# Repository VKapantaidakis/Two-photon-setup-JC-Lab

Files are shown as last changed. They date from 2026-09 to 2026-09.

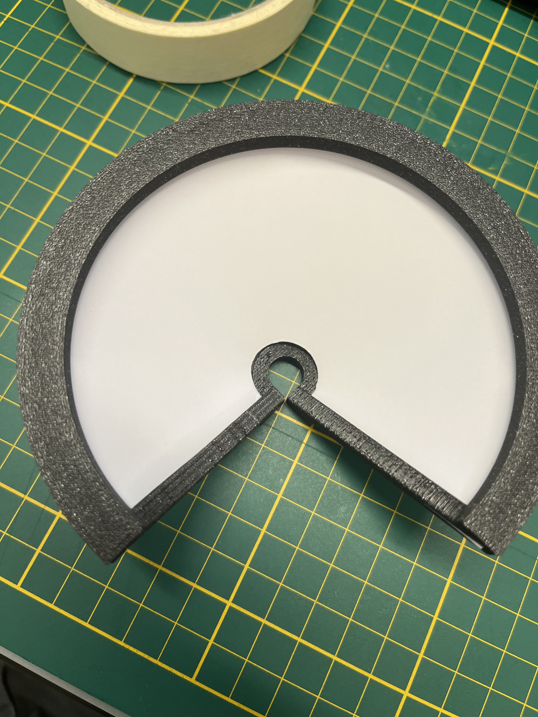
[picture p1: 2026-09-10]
Thesis setup/figures/TWO_PHOTON_SCREEN2.jpeg

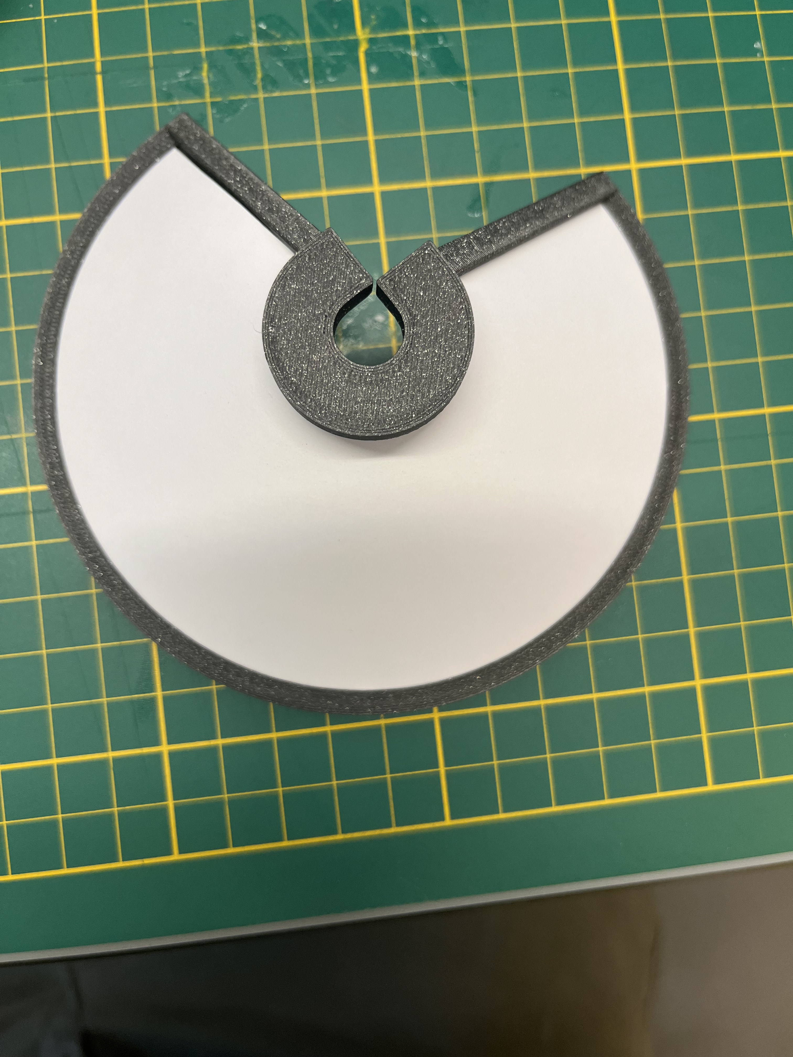
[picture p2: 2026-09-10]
Thesis setup/figures/TWO_PHOTON_SCREEN1.jpeg

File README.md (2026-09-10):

# Two Photon Setup — JC Lab

Two-photon imaging and behaviour setup for tethered *Drosophila*. A **Basler GigE camera** tracks a spherical treadmill through **FicTrac**, a **ViRMEn** virtual world is projected onto a **conical screen**, and an **Arduino** timestamps every two-photon frame trigger so imaging and behaviour can be aligned offline.

**Author:** Vasilis Kapantaidakis
**Lab:** JC Lab (Billeter Lab), Groningen Institute for Evolutionary Life Sciences (GELIFES), University of Groningen
**Experiment type:** two-photon calcium imaging with simultaneous visual-stimulation behaviour in tethered *Drosophila melanogaster* on a spherical treadmill
**Platform:** Ubuntu 24.04 LTS · MATLAB R2014b · FicTrac · ViRMEn · Basler Pylon · Arduino

Everything here was run on a real machine and the commands are reproduced verbatim, including the workarounds for the awkward combinations (a 2014 MATLAB on a 2024 Linux, a Pylon SDK newer than the FicTrac fork expects, GigE over a USB-Ethernet adapter).

> ### ▶ Just want to run an experiment today?
> **[RUN-AN-EXPERIMENT.md](RUN-AN-EXPERIMENT.md)** — the step-by-step checklist: open MATLAB, run the config, start FicTrac, start the scan.
> The numbered `docs/` below are for building the rig from scratch.

---

## Hardware

| Component | Model / notes |
|---|---|
| Camera | Basler **acA1300-60gm**, GigE (Ethernet), 1280×1024 @ 60 fps |
| Camera link | RTL8153 USB-Ethernet adapter (see the MTU caveat in [01](docs/01-basler-camera.md)) |
| Microcontroller | Arduino Uno R3 |
| RTC | DS3231 (I²C) |
| Environment sensor | DHT22 |
| Illumination | IR LED array via IRF520 MOSFET module |
| Projection | projector onto a 3D-printed conical screen ([07](docs/07-3d-printed-parts.md)) |
| Treadmill | patterned foam sphere on an air support |
| Host | Dell Pro 14, Ubuntu 24.04.4 LTS |

## Software stack

```
Basler camera ──GigE──> FicTrac ──(TCP, optional closed loop)──> ViRMEn (MATLAB)
                                                                      │
2P frame TTL ──> Arduino ──USB serial──> arduinoFrameLog ─────────────┘
                                              │
                                              └──> per-frame CSV logs
```

In the **WhiteBack → BlackChamber** protocol documented here, ViRMEn's movement function is `moveWithKeyboard` — the fly does not drive the world. FicTrac records ball motion alongside; closed-loop is a separate protocol.

## Replicate it — follow in order

| # | Document | What it gets you |
|---|---|---|
| ▶ | **[Run an experiment](RUN-AN-EXPERIMENT.md)** | **daily checklist once the rig is built** |
| 00 | [User & OS setup](docs/00-user-setup.md) | Ubuntu user, groups, **Xorg session**, folder layout |
| 01 | [Basler camera](docs/01-basler-camera.md) | Pylon SDK, GigE network, live image |
| 02 | [FicTrac](docs/02-fictrac.md) | Built against Pylon, calibrated, tracking |
| 03 | [MATLAB R2014b](docs/03-matlab.md) | Installed, licensed, **two launchers** |
| 04 | [ViRMEn](docs/04-virmen.md) | Compiled for Linux, worlds rendering |
| 05 | [Arduino / DAQ](docs/05-arduino-daq.md) | Sketch, wiring, serial into MATLAB |
| 06 | [Experiment workflow](docs/06-experiment-workflow.md) | Running a session end to end |
| 07 | [3D printed parts](docs/07-3d-printed-parts.md) | Conical screen and mounts |
| 99 | [Troubleshooting](docs/99-troubleshooting.md) | Every error we hit, and its fix |

## Repository layout

```
matlab/     experiment scripts (see docs/06)
arduino/    daq_frame_logger_v6 sketch
patches/    source patches for FicTrac and ViRMEn
setup/      udev rule, desktop launchers
hardware/   3D print files
docs/       the guides above
```

## Five things that will cost you a day if you skip them

1. **Use an Xorg session, not Wayland.** FicTrac's GUI dies on Wayland with a protocol error. [→ 00](docs/00-user-setup.md)
2. **You need two MATLAB launchers.** `-softwareopengl` makes ViRMEn's design panels render but **segfaults** when an experiment runs; without it the experiment runs but the panels are blank. They cannot be reconciled. [→ 03](docs/03-matlab.md)
3. **MATLAB R2014b on Linux only sees `/dev/ttyS*`.** Your Arduino on `/dev/ttyACM0` is invisible until you symlink it. [→ 05](docs/05-arduino-daq.md)
4. **Do not enable jumbo frames** on a USB-Ethernet adapter. Pylon's optimiser sets MTU 9000, ping still works, and video silently dies. [→ 01](docs/01-basler-camera.md)
5. **One program per device.** Pylon Viewer blocks FicTrac; the DAQ monitor blocks the experiment script. Wait ~8 s after killing a client for the GigE heartbeat to expire. [→ 99](docs/99-troubleshooting.md)

## Citing / reusing this setup

If this documentation helps you build or repair a rig, a note or citation is appreciated:

> Kapantaidakis, V. *Two Photon Setup — JC Lab: a replication guide for a tethered-fly
> two-photon imaging and conical visual stimulation rig.* JC Lab (Billeter Lab),
> University of Groningen, 2026. https://github.com/VKapantaidakis/Two-photon-setup-JC-Lab

The 3D printed optomechanics are a third-party design — see [docs/07](docs/07-3d-printed-parts.md) for attribution.

## Contact

**If you have problems with anything in this repository, contact Vasilis Kapantaidakis:**

- **vaskapant@gmail.com**
- **v.kapantaidakis@student.rug.nl**

JC Lab (Billeter Lab), University of Groningen.

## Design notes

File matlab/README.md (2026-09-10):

# matlab/

Install these into `~/Documents/MATLAB/virmen/experiments/`.

| File | Role |
|---|---|
| `MasterSwitchByDAQ_WhiteBack_BlackChamber.m` | main experiment script (WhiteBack -> BlackChamber) |
| `WhiteBack.m` / `BlackChamber.m` | phase logic; end after `vr.frameThreshold` frames |
| `WhiteBack.mat` / `BlackChamber.mat` | ViRMEn visual worlds |
| `arduinoFrameLog.m` | the single serial reader; logging, live panel, CSV export |
| `plotSession.m` | post-hoc plots + per-phase summary |
| `daq_frame_monitor_v2.m` | standalone DAQ tester (do NOT run alongside the master script) |

All are MATLAB **R2014b** compatible: legacy `serial()` API, no `serialport`,
no `datetime`, no `yyaxis`, and no local functions inside script files.

See [docs/06-experiment-workflow.md](../docs/06-experiment-workflow.md).

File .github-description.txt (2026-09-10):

Paste this into the repo's "About" box on GitHub (gear icon, top right):

DESCRIPTION
-----------
Two-photon imaging + visual stimulation rig for tethered Drosophila by Vasilis Kapantaidakis (JC Lab, University of Groningen). Basler GigE camera, FicTrac treadmill tracking, ViRMEn worlds on a conical screen, Arduino frame-trigger sync. Full setup and replication guide for Ubuntu 24.04 + MATLAB R2014b.

TOPICS (add these tags)
-----------------------
drosophila  two-photon  calcium-imaging  neuroscience  virtual-reality
fictrac  virmen  matlab  arduino  basler  pylon  behaviour  ubuntu
spherical-treadmill  visual-stimulation

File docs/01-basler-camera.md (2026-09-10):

# 01 — Basler GigE camera (Pylon SDK)

Getting a **Basler acA1300-60gm** GigE camera streaming on Ubuntu 24.04.

Pylon is Basler's SDK — the equivalent of Spinnaker for FLIR cameras. If you are adapting a Spinnaker-based protocol, note that **none of the Spinnaker workarounds apply**: no spack, no ffmpeg 4, no `usbfs_memory` service (that is USB3-only), no `flirimaging` group.

---

## 1. Install the Pylon SDK

Download from the [Basler website](https://www.baslerweb.com/en/software/pylon/) (free account required). Install to **`/opt/pylon`** — the FicTrac build in [02](02-fictrac.md) expects that path.

```bash
# .deb package (installs to /opt/pylon by default)
sudo apt install ./pylon_*_amd64.deb

# or from the tarball
cd ~/Downloads
tar -xzf pylon_*_x86_64_setup.tar.gz
sudo mkdir -p /opt/pylon
sudo tar -C /opt/pylon -xzf pylon-*.tar.gz
```

Load the environment (add to `~/.bashrc` so it persists):

```bash
source /opt/pylon/bin/pylon-setup-env.sh /opt/pylon
echo 'source /opt/pylon/bin/pylon-setup-env.sh /opt/pylon' >> ~/.bashrc
echo $PYLON_ROOT          # expect: /opt/pylon
```

Verify the C++ SDK and the GigE transport layer are present — FicTrac links against these:

```bash
ls /opt/pylon/include/pylon/PylonBase.h
ls /opt/pylon/lib | grep libpylon_TL_gige
```

If Pylon Viewer later fails with an `xcb` plugin error, install the Qt runtime pieces:

```bash
sudo apt-get install -y libxcb-xinerama0 libxcb-xinput0 libxcb-cursor0 \
  libxkbcommon-x11-0 libqt5gui5 libqt5widgets5
```

> **Modern Pylon note.** Pylon 7/8 (`libpylonbase.so.12`) reorganised its headers: the transport-specific ones under `pylon/usb/` no longer exist. Use the transport-agnostic `pylon/InstantCameraArray.h` and `Pylon::CInstantCamera`, which drive **both** GigE and USB3. This is exactly the patch FicTrac needs — see [02](02-fictrac.md).

## 2. Network configuration

A GigE camera is a network device on a dedicated link. Reference configuration:

```
enx00e04c68131b   RTL8153 USB-Ethernet, 192.168.4.2/24, MTU 1500, 1000 Mbps  <- CAMERA
  camera:         192.168.4.3, MAC 00:30:53:2c:a0:de   (00:30:53 = Basler OUI)
enp0s31f6         onboard Ethernet, DOWN (unused)
wlp44s0f0         WiFi — the MATLAB licence is host-locked to this MAC. Never disable it.
```

Find your interfaces and which one has a link:

```bash
ip -br link show
ip addr show <camera-interface>
```

Set a static IP on the camera's interface (any private subnet; the camera must be on the same one):

```bash
nmcli con show                                    # find the connection name
nmcli con mod "<connection-name>" ipv4.method manual \
      ipv4.addresses 192.168.4.2/24
nmcli con up "<connection-name>"
```

Find the camera:

```bash
ip neigh show | grep 192.168.4        # look for a 00:30:53:* MAC
ping -c 2 192.168.4.3
```

If it does not appear, use Basler's IP tool — it detects cameras by MAC broadcast even when their IP is wrong for your subnet, and lets you assign one:

```bash
/opt/pylon/bin/ipconfigurator &
```

## 3. Do NOT enable jumbo frames on a USB-Ethernet adapter

Basler ships an optimiser:

```bash
sudo /opt/pylon/bin/PylonGigEConfigurator list      # shows adapters + settings
sudo /opt/pylon/bin/PylonGigEConfigurator auto-opt  # sets MTU 9000, buffers
```

**On the RTL8153 USB-Ethernet adapter this breaks streaming.** The adapter advertises MTU 9000 but cannot deliver it. Small packets (ping) still work, so the fault looks mysterious — video simply stops.

Test the jumbo path explicitly:

```bash
ping -M do -s 8972 -c 3 192.168.4.3    # 8972 + 28 header = 9000, don't-fragment
```

On the reference machine: **100% packet loss**. Revert to 1500 and pin it:

```bash
sudo ip link set <camera-interface> mtu 1500
nmcli con mod "<connection-name>" 802-3-ethernet.mtu 1500
nmcli con up "<connection-name>"
ip link show <camera-interface> | grep -o "mtu [0-9]*"
```

MTU 1500 costs some efficiency, not function. If you use a proper PCIe NIC rather than a USB adapter, re-test the jumbo path — it may work, and 9000 is preferable when it does.

Prefer `auto-opt` only after confirming jumbo frames actually pass. Use `auto-opt`, **not** `auto-all` — the latter also reassigns IPs, which you do not want once addressing works.

## 4. Verify with Pylon Viewer

```bash
source /opt/pylon/bin/pylon-setup-env.sh /opt/pylon
/opt/pylon/bin/pylonviewer &
```

The camera should appear in the device tree. Double-click it, then **Continuous Shot** for live video.

If streaming fails while ping succeeds, check the camera's own packet size: **Transport Layer → GevSCPSPacketSize** (needs Expert/Guru view). It must not exceed the host MTU — set it to 1500 if the host is at 1500.

> **Close Pylon Viewer before running FicTrac.** A GigE camera accepts one controlling application at a time; otherwise FicTrac reports
> `Failed to open ... The device is controlled by another application`.

## 5. Quick health check

```bash
echo "=== camera reachable? ==="
ping -c 2 192.168.4.3
echo "=== link + IP ==="
ip -br addr show <camera-interface>
echo "=== anything holding the camera? ==="
pgrep -a "pylonviewer|configGui|fictrac" || echo "camera is free"
```

---

## Checklist

- [ ] `/opt/pylon` installed, `$PYLON_ROOT` set
- [ ] Camera pings on the dedicated subnet
- [ ] **MTU 1500** confirmed and pinned
- [ ] Live image in Pylon Viewer
- [ ] Pylon Viewer closed again

Next: [02 — FicTrac](02-fictrac.md)

---

*JC Lab, University of Groningen. Problems with this guide? Contact Vasilis Kapantaidakis — vaskapant@gmail.com or v.kapantaidakis@student.rug.nl*

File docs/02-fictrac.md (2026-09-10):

# 02 — FicTrac (built against Pylon)

[FicTrac](https://github.com/rjdmoore/fictrac) reconstructs the path of an animal walking on a patterned sphere. Upstream supports FLIR/Spinnaker cameras; Basler support comes from a community fork, which needs one patch to build against a modern Pylon SDK.

Prerequisite: [01 — Basler camera](01-basler-camera.md) complete, with a live image in Pylon Viewer.

---

## 1. Dependencies

```bash
sudo apt-get update
sudo apt-get install -y \
  git build-essential gcc g++ cmake pkg-config \
  libopencv-dev \
  libboost-all-dev \
  libnlopt-dev libnlopt-cxx-dev \
  libavcodec-dev libavformat-dev libavutil-dev libswscale-dev \
  libgtk2.0-dev yasm unzip tar curl
```

> **Do not install `libavresample-dev`.** Older FicTrac docs list it, but it was removed in FFmpeg 5 (which Ubuntu 24.04 ships) and the package no longer exists — `apt` will fail with "unable to locate package". FicTrac builds fine without it; `libswscale-dev` covers the same ground.

## 2. Clone the Basler fork

```bash
cd ~
git clone https://github.com/neurophysiology-expertise-unit/fictrac-basler.git fictrac
cd fictrac
```

## 3. Patch for modern Pylon

The fork includes a USB3-specific header that **does not exist** in Pylon 7/8:

```
fatal error: pylon/usb/BaslerUsbInstantCameraArray.h: No such file or directory
```

There is no `pylon/usb/` directory in modern Pylon at all. The fix is one line — and it is safe, because the source only ever uses the generic `Pylon::CInstantCamera`, which handles GigE and USB3 alike.

In `include/BaslerSource.h`, line 16:

```diff
-#include <pylon/usb/BaslerUsbInstantCameraArray.h>
+#include <pylon/InstantCameraArray.h>
```

Or apply it directly:

```bash
sed -i 's|#include <pylon/usb/BaslerUsbInstantCameraArray.h>|#include <pylon/InstantCameraArray.h>|' \
  ~/fictrac/include/BaslerSource.h
```

See also `patches/fictrac-BaslerSource.patch`.

## 4. Build

```bash
cd ~/fictrac
source /opt/pylon/bin/pylon-setup-env.sh /opt/pylon
mkdir -p build && cd build
cmake -DBASLER_USB3=ON -DBASLER_DIR="/opt/pylon" ..
cmake --build . --config Release --parallel $(nproc)
```

> The flag is named `BASLER_USB3` but is **correct for a GigE camera**. It enables the Basler code path; Pylon's `CInstantCamera` API drives both transports through the same code. There is no separate GigE flag.

Binaries land in `~/fictrac/bin/`:

```bash
ls -la ~/fictrac/bin/       # expect: fictrac, configGui
```

Optionally make them available everywhere:

```bash
sudo cp ~/fictrac/bin/* /usr/local/bin
```

## 5. Verify without a camera

```bash
cd ~/fictrac/sample
../bin/fictrac config.txt
```

With `src_fn : basler` and no camera attached, the correct output is:

```
Opening Basler Camera...
Error opening capture device! No Basler devices found!
```

That is a **pass** — it proves the Basler code path compiled in and is trying to open a camera.

## 6. Set up an experiment config

```bash
mkdir -p ~/Documents/fictrac-experiments
cp ~/fictrac/sample/config.txt ~/Documents/fictrac-experiments/config.txt
cd ~/Documents/fictrac-experiments
grep -n "src_fn" config.txt        # must read: src_fn : basler
```

## 7. Calibrate with `configGui`

**Run without `sudo`.** GigE cameras need no root (that is a USB3 requirement), and a root GUI process under any display server hits permission problems — under Wayland it fails outright, and even on Xorg you get `QStandardPaths: runtime directory ... is not owned by UID 0`. The `Recorder processing thread unable to set thread priority!` warnings are harmless.

Make sure nothing else holds the camera first:

```bash
pkill -f pylonviewer; pkill -f configGui; pkill -f fictrac
sleep 8                                    # let the GigE heartbeat expire
pgrep -a "pylonviewer|configGui|fictrac" || echo "camera free"
```

Then:

```bash
cd ~/Documents/fictrac-experiments
source /opt/pylon/bin/pylon-setup-env.sh /opt/pylon
~/fictrac/bin/configGui config.txt
```

A successful open looks like:

```
Found 1 Basler device(s). Connecting to index 0...
Opening Basler camera device: acA1300-60gm
Basler camera initialised (1280x1024 @ 59.952 fps)!
```

### Starting from a clean calibration

The sample config ships with the demo video's ROI and transform. To be asked nothing and configure everything fresh:

```bash
cd ~/Documents/fictrac-experiments
cp config.txt config_backup_$(date +%H%M).txt
sed -i '/^roi_/d; /^c2a_r/d; /^c2a_t/d' config.txt
~/fictrac/bin/configGui config.txt
```

### How to answer the prompts

This trips people up, so read it before you start:

- **y/n questions are answered in the terminal.** **ENTER and ESC are keystrokes in the image window** — click the image first, then press them.
- **Answer one prompt at a time.** Typing ahead queues characters in stdin, which later prompts then consume; you end up silently keeping the sample's calibration. If you see prompts answering themselves, that is what happened.
- Answer **n** to "keep the existing …" unless you deliberately want the previous calibration.

### Drawing the ball ROI

- **Single deliberate clicks**, 6–8 points spread around the ball's edge (clock positions 12, 2, 4, 6, 8, 10). Dragging produces clusters of duplicate points and a poor circle fit.
- Right-click removes the last point.
- Click only where the ball's **true circumference** is visible — not along an edge where the fly holder or a pipette cuts across it.

### Check the fit before trusting it

`configGui` writes an image with the fitted circle drawn in red:

```bash
xdg-open ~/Documents/fictrac-experiments/fictrac-configImg.png
```

The circle should sit neatly on the ball's edge. If it does not, redo the ROI — every downstream number depends on it.

## 8. Run tracking

```bash
cd ~/Documents/fictrac-experiments
source /opt/pylon/bin/pylon-setup-env.sh /opt/pylon
~/fictrac/bin/fictrac config.txt
```

A live window shows the ball with the tracking overlay, and numbers stream in the terminal. **Spin the ball by hand** — roll it forward and the forward-motion column should change; rotate it and heading should change. Incoherent numbers mean the calibration is wrong, not the software.

Output files: `*.dat` (one row per frame) and `*.log`.

### Stopping FicTrac

- **ESC** in the FicTrac window (click it first so it has focus) — the clean exit; closes the camera and finishes the `.dat` file.
- **Ctrl+C** in the terminal.
- `pkill -f fictrac` from another terminal; `pkill -9 -f fictrac` if unresponsive (skips cleanup, may truncate output).

Then **wait ~8 s** before starting anything else that uses the camera.

## 9. Closed loop into ViRMEn (optional)

For closed-loop protocols, FicTrac publishes over TCP and MATLAB reads it:

```matlab
vr.socket = tcpclient('127.0.0.1', 3000);
```

Check the socket settings in your config:

```bash
grep -nE "sock|port|out_" config.txt
```

> The **WhiteBack → BlackChamber** protocol in [06](06-experiment-workflow.md) does **not** use this — its movement function is `moveWithKeyboard` and world switching is driven by 2P frame count. FicTrac runs alongside to record ball motion.

---

## Checklist

- [ ] Builds with no errors, `bin/fictrac` and `bin/configGui` present
- [ ] Camera opens: `Basler camera initialised (1280x1024 @ 59.952 fps)`
- [ ] Red circle in `fictrac-configImg.png` sits on the ball
- [ ] Ball motion produces coherent numbers

Next: [03 — MATLAB R2014b](03-matlab.md)

---

*JC Lab, University of Groningen. Problems with this guide? Contact Vasilis Kapantaidakis — vaskapant@gmail.com or v.kapantaidakis@student.rug.nl*

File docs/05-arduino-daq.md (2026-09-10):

# 05 — Arduino / DAQ frame logger

An Arduino Uno timestamps every two-photon frame trigger and streams the record to MATLAB, so imaging frames and behaviour can be aligned offline. It also logs two analog channels, temperature/humidity, and drives the IR illuminator.

Sketch: [`arduino/daq_frame_logger_v6/daq_frame_logger_v6.ino`](../arduino/daq_frame_logger_v6/daq_frame_logger_v6.ino)

---

## 1. Wiring

| Signal | Pin | Notes |
|---|---|---|
| DAQ frame trigger | **D2** (INT0) | BNC centre; shield → Arduino GND. Use `INPUT_PULLUP` if the DAQ output is open-collector |
| IR LED array gate | **D5** (PWM) | to WPM411 / IRF520 MOSFET `SIG`; V− is the switching leg |
| DHT22 data | **D7** | 10 kΩ pull-up to 5 V if using a bare 4-pin sensor |
| DS3231 RTC | **A4** SDA / **A5** SCL | I²C |
| DAQ analog in | **A0**, **A1** | 0–5 V, 10-bit |

## 2. Libraries

Arduino IDE → **Tools → Manage Libraries** (Ctrl+Shift+I), install:

1. **RTClib** by Adafruit
2. **DHT sensor library** by Adafruit — when prompted *"Install all dependencies?"* click **Install All** (it needs **Adafruit Unified Sensor**; the sketch will not compile without it)

`Wire` ships with the IDE.

Set **Tools → Board → Arduino Uno** and **Tools → Port → /dev/ttyACM0**.

> **Port greyed out, or `avrdude: ser_open(): can't open device`?** You are not in the `dialout` group, or you have not logged out and back in since being added. See [00](00-user-setup.md).

## 3. Upload and verify

Upload, then open **Tools → Serial Monitor at 115200 baud**. Expect a header and a heartbeat line once per second:

```
#fmt,seq,epoch_s,ms,micros,a0,a1,tempC,rh,missed
#pins,trig=D2,gate=D5,dht=D7,i2c=A4/A5,analog=A0/A1
#rtc,ok
#stat,frames=0,rate=0.0Hz,missed=0,dhtOk=1,dhtFail=0,T=23.4,RH=41.2,age=120ms,led=255,stream=0
```

**Close the Serial Monitor before using MATLAB.** One program per serial port.

## 4. Serial protocol

Single-character commands, 115200 baud:

| Cmd | Action |
|---|---|
| `S` | start streaming data lines |
| `X` | stop streaming |
| `Z` | zero the frame counter |
| `R` | print statistics now |
| `1` | LEDs full on |
| `0` | LEDs off |
| `B<n>` | LED brightness 0–255 (e.g. `B128`) |
| `T` | DHT self-test (5 reads, interrupt detached) |
| `H` | toggle the 1 Hz heartbeat |
| `?` | print the header block |

One data line per trigger:

```
D,seq,epoch_s,ms,micros,a0,a1,tempC,rh,missed
```

| Field | Meaning |
|---|---|
| `seq` | frame counter since last `Z` — gaps mean frames lost in transit |
| `epoch_s`, `ms` | absolute time from the DS3231 |
| `micros` | Arduino microsecond clock; the precise relative timebase |
| `a0`, `a1` | analog channels, raw 0–1023 |
| `tempC`, `rh` | DHT22 (`nan` until the first good read) |
| `missed` | triggers the sketch itself could not send in time |

Lines beginning `#` are status, not data.

> **v6 fixes a DHT22 bug.** The sensor needs 2 s between samples; v4/v5 forced both a temperature and a humidity read back to back, so humidity always returned NaN. v6 forces one read and takes the companion value from the same cached packet.

## 5. Make the port visible to MATLAB

**MATLAB R2014b on Linux only recognises ports named `/dev/ttyS*`.** Your Arduino on `/dev/ttyACM0` is invisible:

```
Open failed: Port: /dev/ttyACM0 is not available. Available ports: /dev/ttyS4.
```

Symlink it into a name MATLAB accepts:

```bash
sudo ln -sf /dev/ttyACM0 /dev/ttyS101
ls -l /dev/ttyS101
```

`/dev` is rebuilt at boot, so make it permanent with a udev rule (also in `setup/99-arduino-matlab.rules`):

```bash
sudo bash -c 'echo "KERNEL==\"ttyACM[0-9]*\", SYMLINK+=\"ttyS101\"" > /etc/udev/rules.d/99-arduino-matlab.rules'
sudo udevadm control --reload-rules
sudo udevadm trigger
ls -l /dev/ttyS101
```

Now the symlink is recreated automatically whenever an Arduino is plugged in.

## 6. `arduinoFrameLog.m` — the single reader

[`matlab/arduinoFrameLog.m`](../matlab/arduinoFrameLog.m) is the **only** code permitted to open the serial port.

**Why this matters:** a serial line can be read exactly once. If both a logger and the experiment code read the port, they steal lines from each other and both get corrupted data. So `arduinoFrameLog` owns the port and republishes the current frame number to the base-workspace variable `latestArduinoFrame`; everything else reads that variable.

It reads with `fread()` on exactly the bytes available and reassembles lines itself, rather than `fgetl()`, which blocks the ViRMEn render loop when a partial line is in the buffer.

| Command | Action |
|---|---|
| `arduinoFrameLog('init', port, baud)` | open and register the port |
| `arduinoFrameLog('attach', s)` | adopt an existing serial object |
| `arduinoFrameLog('start' / 'stop' / 'zero')` | sketch control |
| `arduinoFrameLog('ledson' / 'ledsoff')` | illuminator |
| `arduinoFrameLog('waitfirst')` | block until the first frame → `[frame, clock]` |
| `arduinoFrameLog('phase', name)` | tag subsequent frames with an experiment phase |
| `n = arduinoFrameLog('poll')` | drain the buffer (non-blocking), returns new frame count |
| `arduinoFrameLog('monitor', N)` | open the live panel, refresh every N frames |
| `arduinoFrameLog('verbose', N)` | console line every N frames (0 = off) |
| `T = arduinoFrameLog('table')` | everything captured so far |
| `arduinoFrameLog('save', dir, tag)` | write CSVs (all frames, per phase, and a clock-sync record) |
| `arduinoFrameLog('stats')` | print a summary |
| `arduinoFrameLog('close')` | stop, close, reset |

Uses the legacy `serial()` API throughout — R2014b has no `serialport()`.

## 7. Test the chain, no ViRMEn

Standalone monitor with live plots ([`matlab/daq_frame_monitor_v2.m`](../matlab/daq_frame_monitor_v2.m)) — set `PORT` at the top, then:

```matlab
clear all
instrreset
daq_frame_monitor_v2
```

Three panels appear: analog channels, temp/humidity, frame timing. **Close the figure to stop** — it then writes a CSV and prints a summary.

`PLOT_EVERY = 10` throttles the *graphics*, not the capture: every frame is still read and stored. Redrawing at 60 Hz would stall the read loop and cause genuine drops. For per-frame visibility use `PRINT_EVERY = 1` (text is far cheaper than graphics).

Or exercise `arduinoFrameLog` directly:

```matlab
instrreset
clear functions
arduinoFrameLog('init','/dev/ttyS101',115200);
arduinoFrameLog('zero'); arduinoFrameLog('start');
arduinoFrameLog('verbose', 1);      % one console line per frame
arduinoFrameLog('monitor', 5);      % live panel
t0 = tic; while toc(t0) < 20, arduinoFrameLog('poll'); pause(0.02); end
arduinoFrameLog('stats');
arduinoFrameLog('close');
```

> **`daq_frame_monitor_v2` and the experiment script cannot run at the same time** — they would both open the port. During experiments use the built-in monitor and console output instead ([06](06-experiment-workflow.md)).

Zero frames but no error means the port opened fine and the DAQ simply is not triggering — check the 2P is scanning and the BNC reaches D2.

---

## Checklist

- [ ] Sketch compiles and uploads; Serial Monitor shows `#fmt` and `#stat` lines
- [ ] Serial Monitor **closed**
- [ ] `/dev/ttyS101` exists, udev rule installed
- [ ] `daq_frame_monitor_v2` captures frames with `dropped 0`

Next: [06 — Experiment workflow](06-experiment-workflow.md)

---

*JC Lab, University of Groningen. Problems with this guide? Contact Vasilis Kapantaidakis — vaskapant@gmail.com or v.kapantaidakis@student.rug.nl*

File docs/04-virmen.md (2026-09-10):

# 04 — ViRMEn compiled for Linux

[ViRMEn](https://pni.princeton.edu/pni-software-tools/virmen) (Virtual Reality MATLAB Engine) generates the virtual world. The distribution ships C/C++ code precompiled for **Windows and macOS only** — there are no Linux binaries, and the build script has no Linux branch. Two patches fix that.

These reproduce, on the public code, the same fixes other labs keep in private forks ("make compilation work on linux" and "enforce C99").

Prerequisite: [03 — MATLAB](03-matlab.md).

---

## 1. Download and lay out the source

The Tank Lab GitHub repo is an **archive of dated release zips**, not the code itself:

```bash
cd ~/Downloads
wget -O ViRMEn.zip https://github.com/Tank-Lab/ViRMEn/archive/refs/heads/master.zip
unzip ViRMEn.zip -d ~/Documents/MATLAB/
ls ~/Documents/MATLAB/ViRMEn-main/Software/       # 2013-02-27 ... 2016-02-12
```

Extract the newest release and flatten it so `virmen.m` sits at the top level:

```bash
mkdir -p ~/Documents/MATLAB/virmen
unzip "$HOME/Documents/MATLAB/ViRMEn-main/Software/ViRMEn 2016-02-12.zip" \
      -d "$HOME/Documents/MATLAB/virmen/"
mv "$HOME/Documents/MATLAB/virmen/ViRMEn 2016-02-12/"* "$HOME/Documents/MATLAB/virmen/"
rmdir "$HOME/Documents/MATLAB/virmen/ViRMEn 2016-02-12"
ls ~/Documents/MATLAB/virmen/          # virmen.m must be here
```

> Quote paths containing `$HOME` rather than using `~` inside quotes — `"~/..."` does not expand and `unzip` will not find the file.

Then clean up the archive you no longer need:

```bash
rm -rf ~/Documents/MATLAB/ViRMEn-main ~/Downloads/ViRMEn.zip
```

## 2. Extra libraries

```bash
sudo apt-get install -y libglfw3 libglfw3-dev libgl1-mesa-dev libglu1-mesa-dev
```

Confirm the **linker symlinks** exist (not just the versioned runtime files):

```bash
ls -l /usr/lib/x86_64-linux-gnu/libglfw.so /usr/lib/x86_64-linux-gnu/libGL.so
```

## 3. Patch 1 — `bin/virmenMake.m`

Two problems: no Linux branch for the GLFW files, and C files compiled in C90 mode, which rejects `//` comments.

**3a. Force C99 on the non-GLFW compile.** In the `if ~isGLFW` branch:

```diff
-            mex(f);
+            mex('CFLAGS="$CFLAGS -std=c99 -fPIC"',f);
```

Without this you get:

```
error: C++ style comments are not allowed in ISO C90
```

**3b. Add a Linux branch.** `computer` returns `GLNXA64` on Linux, which falls through to an error. Insert a case after the `MACI64` one:

```diff
                     elseif strcmp(computer, 'MACI64')
                         mex('-L./GLFW','-v','-lglfw.3', ... ,'-outdir',currentDir,f);
+                    elseif strcmp(computer, 'GLNXA64')
+                        mex('-lglfw','-lGL','CFLAGS="$CFLAGS -std=c99 -fPIC"','-outdir',currentDir,f);
                     else
```

Without it:

```
Error using virmenMake>compilationFunction
Unsupported compilation architecture.
```

See `patches/virmen-virmenMake.patch`.

## 4. Patch 2 — `bin/gui/updateFigures.m`

The GUI builds its movement and transformation menus from platform-specific mex files, with cases for `PCWIN`, `PCWIN64` and `MACI64` — but **not** `GLNXA64`. On Linux the list comes back empty and the GUI crashes on startup:

```
Index exceeds matrix dimensions.
Error in updateFigures (line 494)
        handles.exper.transformationFunction = str2func(str{1});
```

Add a Linux case in **both** blocks — movements (~line 455) and transformations (~line 480):

```diff
         case 'MACI64'
             mf = [mf; dir([path filesep '..' filesep '..' filesep 'movements' filesep '*.mexmaci64'])];
+        case 'GLNXA64'
+            mf = [mf; dir([path filesep '..' filesep '..' filesep 'movements' filesep '*.mexa64'])];
     end
```

```diff
         case 'MACI64'
             mf = [mf; dir([path filesep '..' filesep '..' filesep 'transformations' filesep '*.mexmaci64'])];
+        case 'GLNXA64'
+            mf = [mf; dir([path filesep '..' filesep '..' filesep 'transformations' filesep '*.mexa64'])];
     end
```

Verify both landed:

```bash
grep -c "GLNXA64" ~/Documents/MATLAB/virmen/bin/gui/updateFigures.m    # expect 2
```

See `patches/virmen-updateFigures.patch`.

> These are the only two places in the ViRMEn tree that branch on platform for mex files. Confirm with:
> ```bash
> grep -rn "mexmaci64\|MACI64" ~/Documents/MATLAB/virmen/bin/ | grep -v "_builtin"
> ```
> Everything else that looks Windows-specific (`ispc` guards on GUIDE background colours, `\t` in `textscan`) is harmless on Linux.

## 5. Set the MATLAB path

```bash
cat > ~/Documents/MATLAB/startup.m <<'EOF'
addpath(genpath(fullfile(getenv('HOME'),'Documents','MATLAB','virmen')))
cd(fullfile(getenv('HOME'),'Documents','MATLAB','virmen','experiments'))
EOF
```

## 6. Compile

Launch MATLAB, then in the Command Window:

```matlab
mex -setup
cd(fullfile(getenv('HOME'),'Documents','MATLAB','virmen','bin'))
virmenMake
virmenMake        % run twice - the second pass picks up files the first generated
```

Every file should report `Successfully compiled` and produce a `.mexa64`. Pointer-type warnings from gcc 13 (`assignment to 'mwSize *' from incompatible pointer type`) are **harmless** — that is 2016 code meeting a 2024 compiler.

Confirm the Linux binaries exist:

```bash
ls ~/Documents/MATLAB/virmen/transformations/*.mexa64
ls ~/Documents/MATLAB/virmen/bin/engine/*.mexa64
```

After editing any `.m`, MATLAB caches the old version — run `clear functions; rehash` or restart before testing.

## 7. Verify

From the **DESIGN** launcher (software GL — see [03](03-matlab.md)):

```matlab
virmen
```

The GUI should open with the design panels rendering. Open `experiments/tennisCourt.mat` and press **Run** — a 3D window appears and responds to movement.

> **Blank design panels?** MATLAB is not in software-GL mode. Check `opengl info` → `Software` should be `'true'`. If it says `false`, you launched from the EXPERIMENT icon.
>
> **Segfault on Run?** You are in software GL. Experiments must be run from the **EXPERIMENT** launcher. See [03](03-matlab.md) — this is the central quirk of the whole setup.

If a dirty relaunch after a crash throws:

```
Error using guidata (line 87)
H must be the handle to a figure or figure descendent.
```

clear the stale state:

```matlab
close all force
clear global guifig
clear all
clear functions
rehash
virmen
```

---

## Checklist

- [ ] `virmen.m` at the top level of `~/Documents/MATLAB/virmen/`
- [ ] Both patches applied (`grep -c GLNXA64 .../updateFigures.m` → 2)
- [ ] `virmenMake` completes twice with no errors
- [ ] `.mexa64` files present in `transformations/` and `bin/engine/`
- [ ] tennisCourt runs from the EXPERIMENT launcher

Next: [05 — Arduino / DAQ](05-arduino-daq.md)

---

*JC Lab, University of Groningen. Problems with this guide? Contact Vasilis Kapantaidakis — vaskapant@gmail.com or v.kapantaidakis@student.rug.nl*

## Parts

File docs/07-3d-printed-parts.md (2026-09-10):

# 07 — 3D printed parts

Optomechanical mounting hardware for the rig: printed **optical posts and post holders** used to position the camera, mirrors, projector optics and the fly holder on the breadboard.

---

## Source and attribution

These parts come from the **PLAb: Optical Posts and Post Holders** system by **Louis Edelman (@LowBoom)**:

> https://www.printables.com/model/1729832-plab-optical-posts-and-post-holders

The published set contains 14 files — 8 post holders, 5 posts, and one example assembly (3MF). Only the two variants actually used on this rig are mirrored here; download the rest from the source page if you need other sizes.

> **Licence check before redistributing.** These are a third-party design. The two STEP files in `hardware/3d-prints/` are included for convenience of replication, but confirm the licence terms on the Printables page permit redistribution, and keep the attribution above with any copy. If the licence does not allow it, remove the files from this repo and rely on the link.

## Parts used on this rig

| File | Part | Interpretation of the name |
|---|---|---|
| `hardware/3d-prints/post_L50_A_M6.step` | Optical post | **L50** = 50 mm length · **A** = variant A · **M6** = M6 threaded interface |
| `hardware/3d-prints/holder_w50_h75_lr_M6.step` | Post holder | **w50** = 50 mm width · **h75** = 75 mm height · **lr** = left/right clamp variant · **M6** = M6 mounting |

Both were exported from Onshape as **STEP AP242**.

<!-- TODO (Vasilis): confirm the "A" and "lr" variant meanings against the source page,
     and record how many of each are used on the rig and for what (camera arm,
     projector mount, fly holder, etc.). -->

## Hardware required

The M6 designation means these interface with standard metric optomechanics:

- **M6 screws** for the breadboard interface (length depends on breadboard thickness)
- **M6 threaded inserts** — heat-set brass inserts are the usual approach for printed parts; printed threads work but wear quickly under repeated adjustment
- Standard optical breadboard with M6 tapped holes

<!-- TODO (Vasilis): record the exact screw lengths and insert part numbers used. -->

## Print settings

<!-- TODO (Vasilis): fill in from your actual prints. The source page does not
     publish recommended settings, so the numbers below are placeholders to be
     replaced with what worked. -->

| Setting | Value |
|---|---|
| Printer | *(to fill in)* |
| Material | *(PLA / PETG / ASA — PETG or ASA preferred for dimensional stability under lamp heat)* |
| Layer height | *(to fill in)* |
| Infill | *(to fill in — posts want high infill or solid for rigidity)* |
| Perimeters | *(to fill in)* |
| Supports | *(to fill in)* |
| Orientation | *(to fill in — posts printed vertically are weakest along the layer lines; consider printing horizontally or increasing perimeters)* |

**Rigidity matters more than speed here.** A post that flexes moves the camera between sessions and invalidates the FicTrac calibration ([02](02-fictrac.md)), which is tied to the exact camera position.

## Assembly notes

<!-- TODO (Vasilis): photograph the assembled mounts and describe which part
     holds what. A photo per mount point is worth more than paragraphs. -->

## Why this matters for the data

The FicTrac camera-to-animal transform is calibrated for one specific camera pose. If a printed mount creeps, slips or is disturbed, the calibration silently degrades — the tracking still runs, the numbers still look plausible, and the ball motion is wrong.

Practical consequences:

- Tighten and, where possible, mark mount positions so drift is visible.
- Re-run `configGui` after any change to the camera position ([02](02-fictrac.md)).
- Record in the session metadata when mounts were adjusted.

---

Next: [99 — Troubleshooting](99-troubleshooting.md)

---

*JC Lab, University of Groningen. Problems with this guide? Contact Vasilis Kapantaidakis — vaskapant@gmail.com or v.kapantaidakis@student.rug.nl*

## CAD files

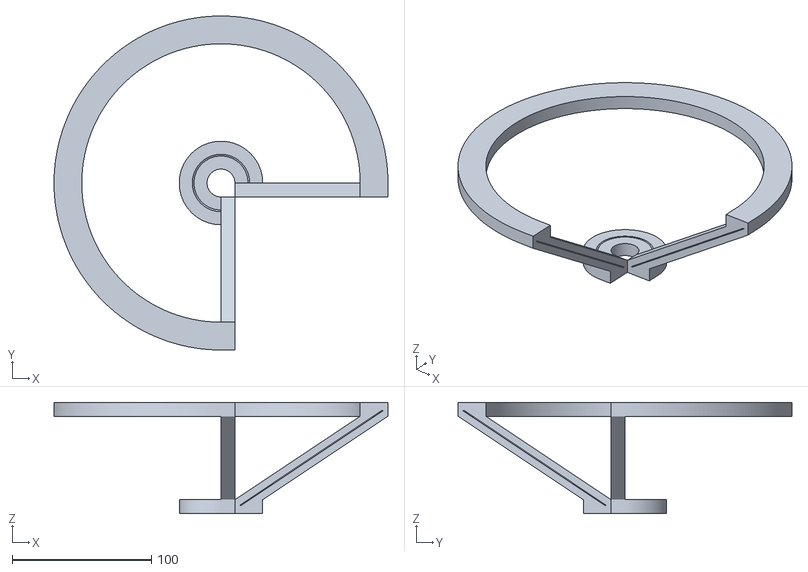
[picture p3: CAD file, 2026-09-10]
Thesis setup/hardware/Full screen Max Planck (Philip).stl
240.0 x 240.0 x 80.0

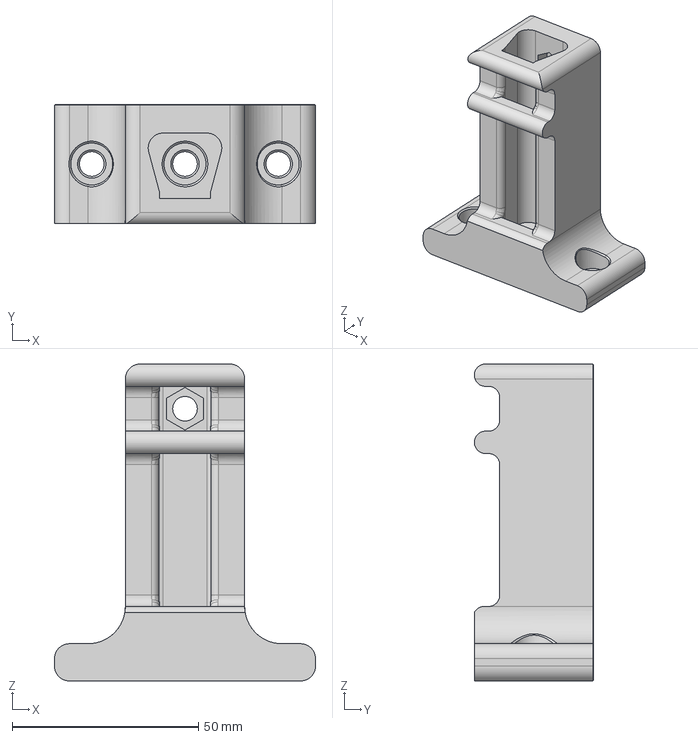
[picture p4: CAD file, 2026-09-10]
hardware/3d-prints/holder_w50_h75_lr_M6.step
70.0 x 32.0 x 85.0 mm

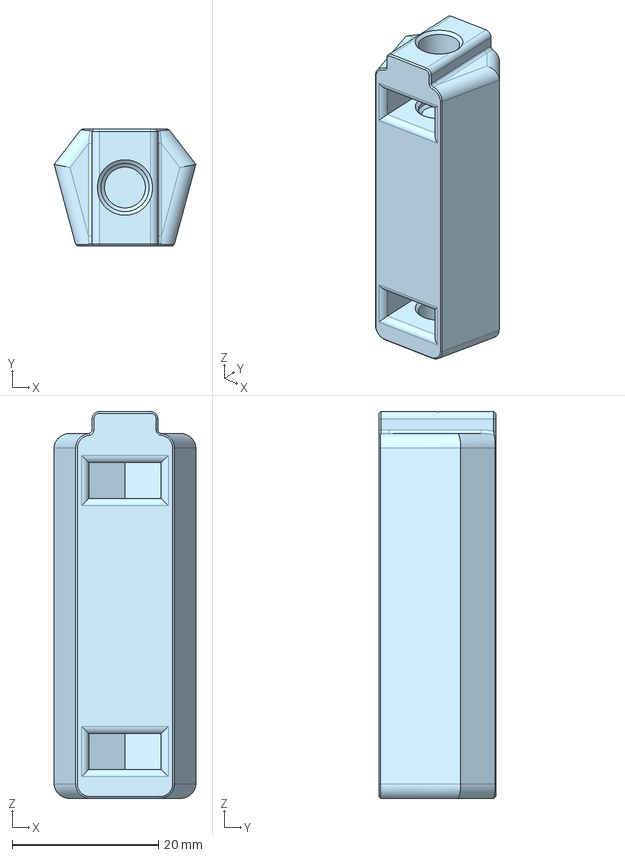
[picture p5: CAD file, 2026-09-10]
hardware/3d-prints/post_L50_A_M6.step
19.4 x 16.0 x 53.0 mm

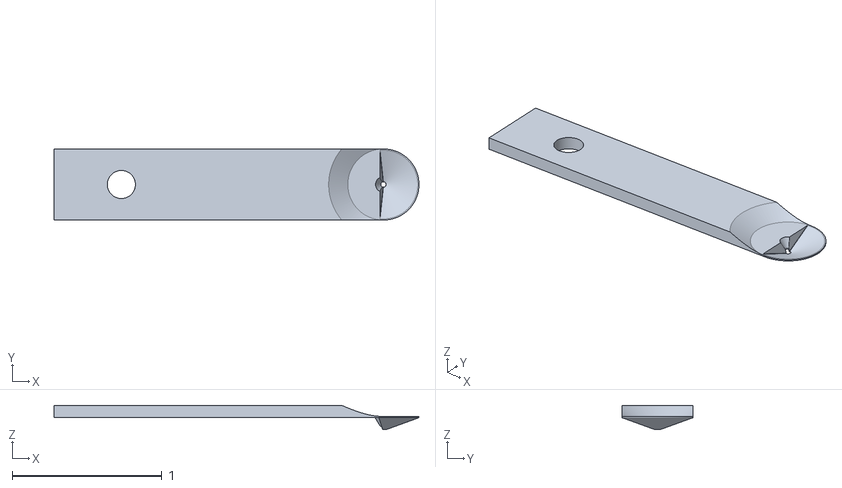
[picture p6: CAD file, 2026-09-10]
Thesis setup/hardware/Flyplate5.stl
2.44 x 0.475 x 0.162

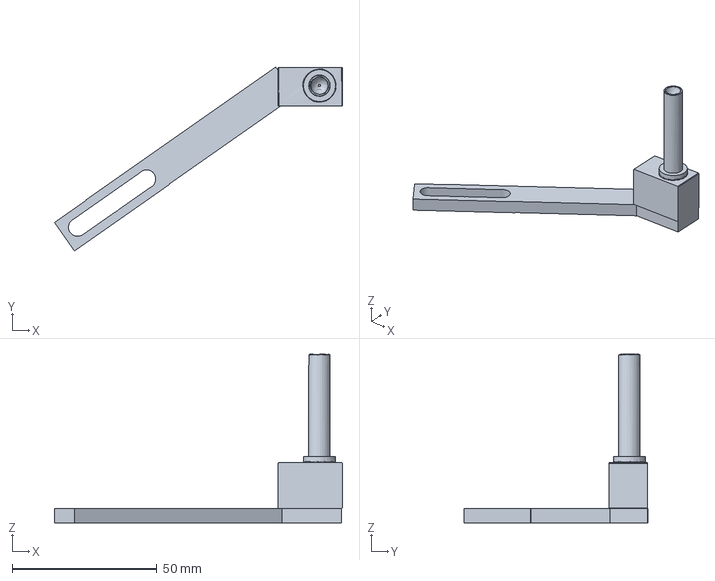
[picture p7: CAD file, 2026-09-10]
Thesis setup/hardware/ball 6mm holder 32mm (1).3mf
99.4 x 63.5 x 58.2 mm

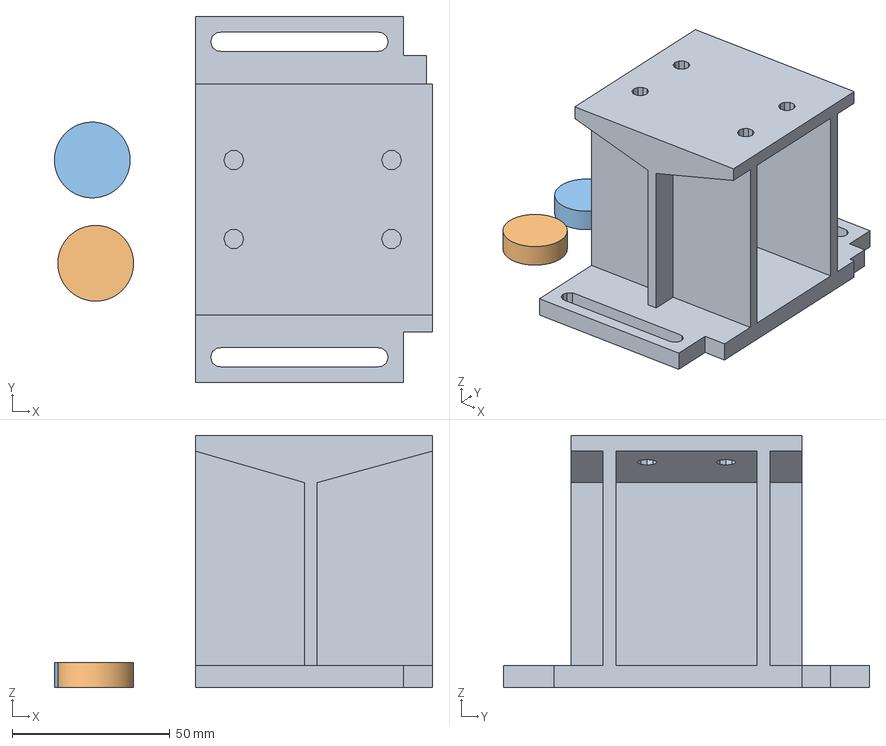
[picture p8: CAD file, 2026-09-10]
Thesis setup/hardware/mirror holder.3mf
119.8 x 116.0 x 80.0 mm
mirror holder.stl
Shape-Cylinder x 2

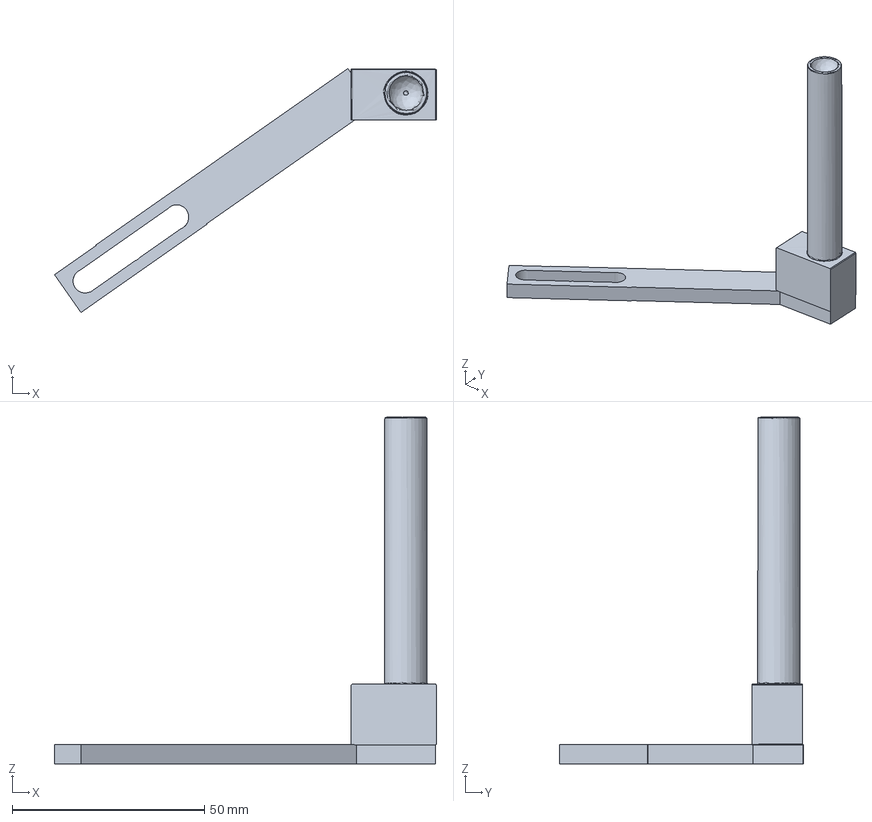
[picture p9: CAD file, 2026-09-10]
Thesis setup/hardware/ball 9mm holder 65mm (1).3mf
99.4 x 63.5 x 90.2 mm

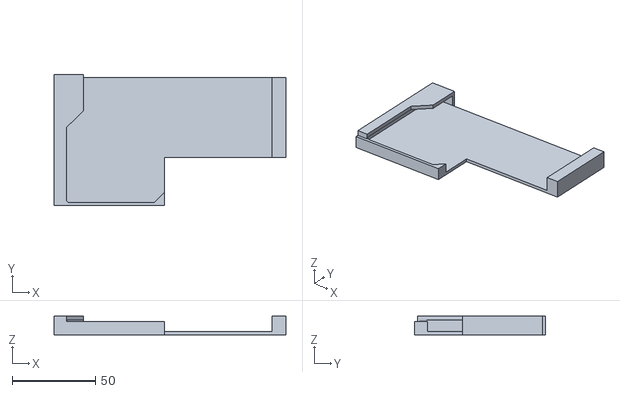
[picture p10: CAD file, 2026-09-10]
Thesis setup/hardware/projector holdercad.stl
139.7 x 79.0 x 11.4

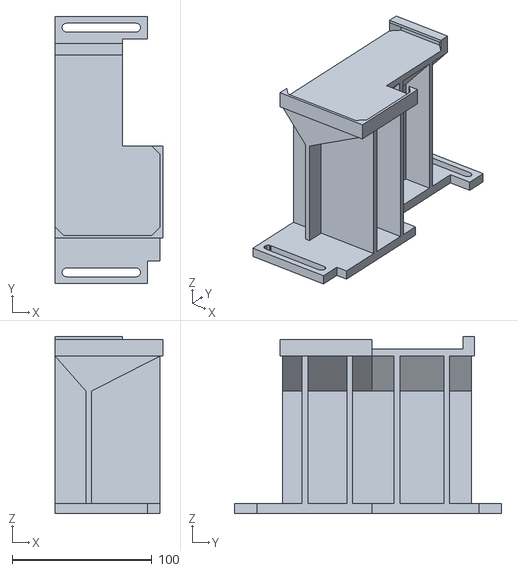
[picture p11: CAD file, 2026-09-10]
Thesis setup/hardware/projector holder hight adjustable.stl
77.0 x 191.0 x 126.5

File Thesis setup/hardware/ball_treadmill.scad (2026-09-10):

// OpenSCAD editing scaffold for:
// Ball_Treadmill_with_Nozzle_alligned.stl
//
// - Bounding box from the STL:
//   X: 99.356 mm, Y: 63.467 mm, Z: 39.863 mm

$fa = 6;
$fs = 0.8;

// ---------- USER CONTROLS ----------
show_original = true;
center_model  = false;

pos   = [0, 0, 0];
rot   = [0, 0, 0];
scale_xyz = [1, 1, 1];

// Easy edit toggles
make_left_right_copy = false;
copy_spacing = 120;

cut_bottom_flat = false;
cut_bottom_z = 0;

add_mount_plate = false;
plate_size = [110, 75, 4];
plate_pos  = [60, 70, -4];

add_holes = false;
hole_d = 4;
hole_spacing = [80, 45];
hole_center = [60, 70, 0];

// ---------- SOURCE STL ----------
module source_mesh() {
    import("Ball_Treadmill_with_Nozzle_alligned.stl", convexity=20);
}

module model_raw() {
    translate(pos)
    rotate(rot)
    scale(scale_xyz)
    if (center_model)
        translate([-60, -69, -20]) // rough visual centering offset for this STL
            source_mesh();
    else
        source_mesh();
}

module editable_model() {
    difference() {
        union() {
            model_raw();

            if (add_mount_plate)
                translate(plate_pos)
                    cube(plate_size);
        }

        if (cut_bottom_flat)
            translate([-200, -200, -200])
                cube([400, 400, 200 + cut_bottom_z]);

        if (add_holes)
            for (sx = [-1, 1], sy = [-1, 1])
                translate([
                    hole_center[0] + sx * hole_spacing[0] / 2,
                    hole_center[1] + sy * hole_spacing[1] / 2,
                    -20
                ])
                    cylinder(d=hole_d, h=100, $fn=48);
    }
}

module final_model() {
    if (make_left_right_copy) {
        translate([-copy_spacing/2, 0, 0]) editable_model();
        translate([ copy_spacing/2, 0, 0]) mirror([1,0,0]) editable_model();
    } else {
        editable_model();
    }
}

// ---------- HELPERS ----------
// Example add-on geometry block. Duplicate/edit as needed.
module add_block(block_pos=[0,0,0], block_size=[10,10,10]) {
    translate(block_pos) cube(block_size);
}

module add_cylinder(cyl_pos=[0,0,0], d=10, h=10, axis="z") {
    translate(cyl_pos)
    if (axis == "x") rotate([0,90,0]) cylinder(d=d, h=h, $fn=64);
    else if (axis == "y") rotate([-90,0,0]) cylinder(d=d, h=h, $fn=64);
    else cylinder(d=d, h=h, $fn=64);
}

// ---------- OUTPUT ----------
if (show_original)
    final_model();

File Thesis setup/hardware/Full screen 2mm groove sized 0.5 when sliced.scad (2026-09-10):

// =====================================================
// ONE SIDE ONLY
// - bottom ring = 135°
// - flipped top ring = 135°
// - groove unchanged
// - male plug on SIDE FACE at 135° of bottom ring
// - female slot on SIDE FACE at 135° of top ring
// =====================================================

phi_deg = 56.3;
ring_thickness = 10;
radial_wall    = 20;
groove_depth   = 4;
groove_width   = 2;

top_inner_d    = 200;
bottom_inner_d = 20;

ring_angle     = 270;
ring_gap       = 60;

$fn = 220;

// =====================================================
// plug / slot sizes
// =====================================================
plug_out       = 4;     // how far it sticks out of the side face
plug_wide      = 6;     // width across the ring thickness direction
plug_tall      = 4;     // height in z

fit_clearance  = 0.3;   // female slot extra size

// choose which flat side face gets the connector
side_angle = ring_angle;   // 135° side face

// =====================================================
// Derived values
// =====================================================
delta_r = groove_depth * tan(phi_deg);

top_clear_r    = top_inner_d / 2;
top_outer_r    = top_clear_r + radial_wall;

bottom_clear_r = bottom_inner_d / 2;
bottom_outer_r = bottom_clear_r + radial_wall;

top_groove_center_r    = (top_clear_r + top_outer_r) / 2;
bottom_groove_center_r = (bottom_clear_r + bottom_outer_r) / 2;

// middle radius of each ring wall
bottom_mid_r = (bottom_clear_r + bottom_outer_r) / 2;
top_mid_r    = (top_clear_r + top_outer_r) / 2;

// radial thickness of each ring wall
wall_mid_span = radial_wall / 2;

// bottom ring: z = 0 .. ring_thickness
// top ring flipped: bottom face sits above by ring_gap
top_translate_z = 2 * ring_thickness + ring_gap;



// =====================================================
// Bottom ring
// groove in TOP face, leaning inward
// male plug added on 135° side face
// =====================================================
module bottom_ring_part()
{
    union()
    {
        difference()
        {
            rotate_extrude(angle = ring_angle)
                polygon([
                    [bottom_clear_r, 0],
                    [bottom_outer_r, 0],
                    [bottom_outer_r, ring_thickness],
                    [bottom_clear_r, ring_thickness]
                ]);

            translate([0,0,ring_thickness - groove_depth])
                rotate_extrude(angle = ring_angle)
                    polygon([
                        [bottom_groove_center_r - groove_width/2, groove_depth],
                        [bottom_groove_center_r + groove_width/2, groove_depth],
                        [bottom_groove_center_r + groove_width/2 - delta_r, 0],
                        [bottom_groove_center_r - groove_width/2 - delta_r, 0]
                    ]);
        }

    }
}

// =====================================================
// Top ring (flipped)
// groove faces downward
// =====================================================
module top_ring_part_flipped()
{
    translate([0,0,top_translate_z])
        mirror([0,0,1])
            difference()
            {
                rotate_extrude(angle = ring_angle)
                    polygon([
                        [top_clear_r, 0],
                        [top_outer_r, 0],
                        [top_outer_r, ring_thickness],
                        [top_clear_r, ring_thickness]
                    ]);

                translate([0,0,ring_thickness - groove_depth])
                    rotate_extrude(angle = ring_angle)
                        polygon([
                            [top_groove_center_r - groove_width/2, groove_depth],
                            [top_groove_center_r + groove_width/2, groove_depth],
                            [top_groove_center_r + groove_width/2 + delta_r, 0],
                            [top_groove_center_r - groove_width/2 + delta_r, 0]
                        ]);
            }
}



// =====================================================
// One side assembly
// =====================================================
module one_side()
{
    union()
    {
        bottom_ring_part();
        top_ring_part_flipped();
        
    }
}

one_side();

// =====================================================
// Bar
// =====================================================
module Bar()

{
    difference()
    {
        union()
        {
            // ---------------------------------------------
            // bottom block
            // ---------------------------------------------
            polyhedron(
                points = [
                    [10,0,0],    // 0
                    [30,0,0],    // 1
                    [30,-10,0],  // 2
                    [10,-10,0],  // 3
                    [10,0,10],   // 4
                    [30,0,10],   // 5
                    [30,-10,10], // 6
                    [10,-10,10]  // 7
                ],
                faces = [
                    [0,2,1], [0,3,2],   // bottom
                    [4,5,6], [4,6,7],   // top
                    [0,1,5], [0,5,4],   // front
                    [1,2,6], [1,6,5],   // right
                    [2,3,7], [2,7,6],   // back
                    [3,0,4], [3,4,7]    // left
                ],
                convexity = 10
            );

            // ---------------------------------------------
            // top block
            // ---------------------------------------------
            polyhedron(
                points = [
                    [100,0,70],    // 0
                    [120,0,70],    // 1
                    [120,-10,70],  // 2
                    [100,-10,70],  // 3
                    [100,0,80],    // 4
                    [120,0,80],    // 5
                    [120,-10,80],  // 6
                    [100,-10,80]   // 7
                ],
                faces = [
                    [0,2,1], [0,3,2],   // bottom
                    [4,5,6], [4,6,7],   // top
                    [0,1,5], [0,5,4],   // front
                    [1,2,6], [1,6,5],   // right
                    [2,3,7], [2,7,6],   // back
                    [3,0,4], [3,4,7]    // left
                ],
                convexity = 10
            );

            // ---------------------------------------------
            // middle connector
            // ---------------------------------------------
            polyhedron(
                points = [
                    [10,0,10],     // 0
                    [30,0,10],     // 1
                    [30,-10,10],   // 2
                    [10,-10,10],   // 3
                    [100,0,70],    // 4
                    [120,0,70],    // 5
                    [120,-10,70],  // 6
                    [100,-10,70]   // 7
                ],
                faces = [
                    [0,2,1], [0,3,2],   // lower end
                    [4,5,6], [4,6,7],   // upper end
                    [0,1,5], [0,5,4],   // front side
                    [1,2,6], [1,6,5],   // right side
                    [2,3,7], [2,7,6],   // back side
                    [3,0,4], [3,4,7]    // left side
                ],
                convexity = 10
            );
        }

        // ---------------------------------------------
        // groove cutter
        // made slightly bigger in y so it fully passes through
        // ---------------------------------------------
        polyhedron(
            points = [
                [15.4023,  1,  6],   // 0
                [13.4023,  1,  6],   // 1
                [117.3977, 1, 74],   // 2
                [115.3977, 1, 74],   // 3
                [15.4023,-11, 6],    // 4
                [13.4023,-11, 6],    // 5
                [117.3977,-11,74],   // 6
                [115.3977,-11,74]    // 7
            ],
            faces = [
                [0,1,3], [0,3,2],    // front end
                [4,6,7], [4,7,5],    // back end
                [0,4,5], [0,5,1],    // lower side
                [1,5,7], [1,7,3],    // left side
                [3,7,6], [3,6,2],    // upper side
                [2,6,4], [2,4,0]     // right side
            ],
            convexity = 10
        );
    }
}

Bar();

// =====================================================
// Bar
// =====================================================
module Bartwo()
{

rotate([0,0,270])
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

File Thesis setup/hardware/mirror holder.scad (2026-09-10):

Beam_hight = 134; //hight of beam center
Beam_grain = 25; //align beam with center of M6 grooves
M6_groove = 6.3; //width of M6 grooves (M6 = 6mm)
M6_wall = 8; //wall for the M6 groove
M6_length = 50; //length of the M6 groove
M6_grid = 25; //distance between M6 holes

Holder_thiccness = 5; //thicness of the projector holder plate
Holder_wall = 2; //thicness of projector holder walls
Holder_wedge = 6; //wedges at the corners of the holder
Beam_side_adjust = 13; //ring outer edge to side of projector
Beam_height_adjust = 6; //ring outer edge to bottom of projector

Base_plate_higth = 7; //thicness of baseplate of projector
Support_wall = 4; //thicness of support structure
Support_heigth = 10; //heigth off angled support

Projector_width = 73.2; //long side of projector
Projector_width_thicc = 73.2; //long side at thiccer section
Projector_depth = 73.2; //short side of projector at thin section
Projector_depth_thicc = 75.2; //short side of projector at thicc section

// =====================================================
// Derived values
// =====================================================

Plate_hight = 80; //hight of plate the projecter will be resting on, beam diameter is 21mm, lens edge is at 6mm
M6_offset = 13.4; //M6 alignment distance
Plate_base = Plate_hight - Holder_thiccness;
Projecter_depth_outskirt = Projector_depth_thicc - Projector_depth; //how much the thicc section of the projector extends beyond the short section
M6_diameter = M6_groove/2; //M6 hole diameter
Base_start = M6_wall - M6_offset; // attach baseplate to m6 groove
Base_extend = 82.2; //attach baseplate to m6 groove

Support  = Support_wall / 2; //middle of support wall
Long_support = Projector_depth /2; //middle of thin long pojector side
Thicc_support = Projector_width_thicc /6; //quarter points thicc section
Thicc_support_edge = Long_support-Support+Projecter_depth_outskirt; //extention of the supports at thicc section to the end of the projector
Thin_support = (Projector_width - Projector_width_thicc) /4; //quarter points thin section
Support_angle_base = Plate_base - Support_heigth; //heigth at which angled support start

Wedge_root = sqrt(2* pow(Holder_wedge,2)); //size of cube to cut wedge


// =====================================================
// Projector holder
// =====================================================
module holder ()

{

        {
            // ---------------------------------------------
            // Projector outskirt block
            // ---------------------------------------------
            difference()
            {
            polyhedron(
                points = [
                    [Projector_depth,0,Plate_hight],    // 0
                    [Projector_depth_thicc,0,Plate_hight],    // 1
                    [Projector_depth_thicc,Projector_width_thicc,Plate_hight],  // 2
                    [Projector_depth,Projector_width_thicc,Plate_hight],  // 3
                    [Projector_depth,0,Plate_base],   // 4
                    [Projector_depth_thicc,0,Plate_base],   // 5
                    [Projector_depth_thicc,Projector_width_thicc,Plate_base], // 6
                    [Projector_depth,Projector_width_thicc,Plate_base]  // 7
                ],
                faces = [
                    [0,2,1], [0,3,2],   // bottom
                    [4,5,6], [4,6,7],   // top
                    [0,1,5], [0,5,4],   // front
                    [1,2,6], [1,6,5],   // right
                    [2,3,7], [2,7,6],   // back
                    [3,0,4], [3,4,7]    // left
                ],
                convexity = 10
            );
            
            union(){
            translate([62.2,24.1,Plate_hight])
            cylinder(10, 3.15, 3.15, center = true);
            
            translate([62.2,49.1,Plate_hight])
            cylinder(10, 3.15, 3.15, center = true);
            }
        }

            // ---------------------------------------------
            // Projector long block
            // ---------------------------------------------
                        difference()
            {
        
        polyhedron(
                points = [
                    [0,0,Plate_hight],    // 0
                    [Projector_depth,0,Plate_hight],    // 1
                    [Projector_depth,Projector_width,Plate_hight],  // 2
                    [0,Projector_width,Plate_hight],  // 3
                    [0,0,Plate_base],   // 4
                    [Projector_depth,0,Plate_base],   // 5
                    [Projector_depth,Projector_width,Plate_base], // 6
                    [0,Projector_width,Plate_base]  // 7
                ],
                faces = [
                    [0,2,1], [0,3,2],   // bottom
                    [4,5,6], [4,6,7],   // top
                    [0,1,5], [0,5,4],   // front
                    [1,2,6], [1,6,5],   // right
                    [2,3,7], [2,7,6],   // back
                    [3,0,4], [3,4,7]    // left
                ],
                convexity = 10
            );
            
                        union(){
            translate([12.2,24.1,Plate_hight])
            cylinder(10, 3.15, 3.15, center = true);
            
            translate([12.2,49.1,Plate_hight])
            cylinder(10, 3.15, 3.15, center = true);
                                       
            translate([62.2,24.1,Plate_hight])
            cylinder(10, 3.15, 3.15, center = true);
            
            translate([62.2,49.1,Plate_hight])
            cylinder(10, 3.15, 3.15, center = true);        
            }
       
        }
     
        }

}

holder ();

// =====================================================
// Base plate
// =====================================================
module base ()

{

        {
            // ---------------------------------------------
            // Projector outskirt block
            // ---------------------------------------------
            polyhedron(
                points = [
                    [Projector_depth,Base_start,Base_plate_higth],    // 0
                    [Projector_depth_thicc,Base_start,Base_plate_higth],    // 1
                    [Projector_depth_thicc,Projector_width_thicc,Base_plate_higth],  // 2
                    [Projector_depth,Projector_width_thicc,Base_plate_higth],  // 3
                    [Projector_depth,Base_start,0],   // 4
                    [Projector_depth_thicc,Base_start,0],   // 5
                    [Projector_depth_thicc,Projector_width_thicc,0], // 6
                    [Projector_depth,Projector_width_thicc,0]  // 7
                ],
                faces = [
                    [0,2,1], [0,3,2],   // bottom
                    [4,5,6], [4,6,7],   // top
                    [0,1,5], [0,5,4],   // front
                    [1,2,6], [1,6,5],   // right
                    [2,3,7], [2,7,6],   // back
                    [3,0,4], [3,4,7]    // left
                ],
                convexity = 10
            );

            // ---------------------------------------------
            // Projector long block
            // ---------------------------------------------
            polyhedron(
                points = [
                    [0,Base_start,Base_plate_higth],    // 0
                    [Projector_depth,Base_start,Base_plate_higth],    // 1
                    [Projector_depth,Base_extend,Base_plate_higth],  // 2
                    [0,Base_extend,Base_plate_higth],  // 3
                    [0,Base_start,0],   // 4
                    [Projector_depth,Base_start,0],   // 5
                    [Projector_depth,Base_extend,0], // 6
                    [0,Base_extend,0]  // 7
                ],
                faces = [
                    [0,2,1], [0,3,2],   // bottom
                    [4,5,6], [4,6,7],   // top
                    [0,1,5], [0,5,4],   // front
                    [1,2,6], [1,6,5],   // right
                    [2,3,7], [2,7,6],   // back
                    [3,0,4], [3,4,7]    // left
                ],
                convexity = 10
            );

        }

}

base ();


// =====================================================
// M6 grooves
// =====================================================
module M6 ()
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

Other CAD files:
Thesis setup/hardware/Full screen 2mm groove (2).stl
Thesis setup/hardware/Full screen 2mm groove (1).stl
Thesis setup/hardware/Full screen 2mm groove sized 0.5 when sliced.stl
Thesis setup/hardware/Full screen Max Planck (Philip).scad
Thesis setup/hardware/mirror holder.stl
Thesis setup/hardware/projector holder hight adjustable.scad

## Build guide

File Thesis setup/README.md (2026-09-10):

# Thesis setup

Design, build and calibration material for the **conical visual stimulation system** - the rig used for behavioural testing and two-photon calcium imaging in *Drosophila melanogaster*.

This folder is the archived content of the original project repository. It documents **how the rig was designed and built**; the numbered guides in [`../docs/`](../docs/) document **how to install and operate the software** on the Ubuntu machine.

**Author:** Vasilis Kapantaidakis - JC Lab (Billeter Lab), University of Groningen

---

## The two screens - key numbers

Two conical rear-projection screens were built from the same parametric design.

| | Behavioural arena screen | Two-photon screen |
|---|---|---|
| Visible diameter | 220 mm -> 40 mm | 110 mm -> 20 mm |
| Height | 60 mm | 30 mm |
| Print file | `Full screen Max Planck (Philip).stl` | `Full screen 2mm groove sized 0.5 when sliced.stl` |
| Relationship | full size | **the same design sliced at 0.5 scale** |

### Paper cone templates (midline / centering check)

Generated with **templatemaker.nl/en/cone**, printed at 100% scale on A4, and used to find the midline before the rear-projection film was fitted.

Two-photon screen:

    BOTTOM = 113 mm    TOP = 17 mm    H = 32 mm    A4, mm
    https://www.templatemaker.nl/en/cone/?BOTTOM=113&TOP=17&H=32&PAGEPRESET=A4&UNITS=mm

Behavioural arena screen:

    BOTTOM = 226 mm    TOP = 34 mm    H = 64 mm    A4, mm
    https://www.templatemaker.nl/en/cone/?BOTTOM=226&TOP=34&H=64&PAGEPRESET=A4&UNITS=mm

> **Note on the numbers.** The template values above (113/17/32 and 226/34/64) are the *corrected* ones and supersede the earlier draft figures of 110/20/30 and 220/40/60 that still appear in some places. The template dimensions are the outer paper geometry; the "visible diameter" figures in the table above are the screen aperture. Use the template values when generating a new cone.

---

## What is in here

| Folder | Contents |
|---|---|
| `hardware/` | All STL, 3MF and OpenSCAD files for printed parts, with a README explaining each one |
| `calibration/` | Cone templates and projector/mirror/screen alignment, including the projection-analysis PDF |
| `docs/` | `APPENDIX_TECHNICAL_PROTOCOL.tex` - the full thesis technical appendix, plus the repository manifest |
| `figures/` | Setup photographs: both screens, the template/midline step, the fly preparation, the imaging area of interest |
| `matlab_virmen/` | The original MATLAB R2018a / ViRMEn worlds and master scripts |
| `arduino/` | The original TTL frame-counter sketch |
| `analysis/` | Behavioural and calcium-imaging analysis notes, and the ImageJ to Excel workflow template |

Also here: `README-original-repo.md` (the original repository README) and `gitignore-original.txt` (its ignore rules, renamed so they do not silently exclude files from this repository).

## Optical setup

- Texas Instruments **DLP3010 LightCrafter** projector
- **45 degree folding mirror** to keep the projector clear of the objective
- Rear-projection film in the printed conical support
- 3D-printed height-adjustable projector holder, mirror holder, screen mounts

The projector, mirror and cone are **mechanically aligned first**; software offsets only correct small residual error. The alignment grid uses concentric circles, radial spokes and crosshairs.

## 3D printing

Printed on an **Original Prusa XL** (5-toolhead, enclosed) in **Prusament PLA Galaxy Black**. A matte charcoal-black PLA was considered as an alternative to reduce reflections from the printed parts - worth trying, since stray light off the cone reaches the animal.

Parts: conical screens (both scales), projector holder, mirror holder, circular screen mounts, fly plate, and 6 mm / 9 mm ball holders. See `hardware/3d_prints/README.md` for the file-by-file breakdown.

> **Duplicate files.** `Full screen 2mm groove (1).stl` and `(2).stl` are almost certainly the same file saved twice - both are 269,684 bytes. All four screen STLs share that size, which is expected rather than suspicious: scaling an STL does not change its triangle count, so the 0.5-scale two-photon screen is byte-for-byte the same size as the full-size one. Worth pruning at some point; kept here for completeness.

## Technical appendix

`docs/APPENDIX_TECHNICAL_PROTOCOL.tex` is the complete written protocol, covering: required components, conical screen design, 3D printing and assembly, projection-path geometry, optical alignment, spectral filtering, MATLAB/ViRMEn workflow, Arduino synchronisation, behavioural implementation, setup checklist and troubleshooting.

## Analysis

Calcium imaging follows an **ImageJ/Fiji to Excel** route: ROI mean intensities are exported per frame, then baseline-normalised (dF/F) against pre-stimulus frames and aligned to the black/white stimulus epochs.

`analysis/calcium_imaging/Results_darktowhite1518.csv.xlsx` is **real data from a dark-to-white recording**, five ROIs, kept as a worked template. To reuse it: copy it first, replace the ImageJ/Fiji export, and check the formula columns still point at the right columns. Record the baseline frame range and the stimulus onset/offset frames for each experiment - the workbook does not carry them.

The final two-photon protocol used black and white visual stimulation, **1500 imaging frames per stimulus followed by a 300-frame break**.

---

## Relationship to the rest of this repository

| This folder (`Thesis setup/`) | The rest of the repo |
|---|---|
| MATLAB **R2018a**, Windows | MATLAB **R2014b**, Ubuntu 24.04 |
| Original design and build record | Current working installation |
| `frame_counter.ino` - simple `FRAME,n` counter | `daq_frame_logger_v6.ino` - RTC timestamps, analog channels, temp/RH |
| `MasterSwitchByDAQ600*.m` | `MasterSwitchByDAQ_WhiteBack_BlackChamber.m` |

The scripts here are the **earlier generation**. The versions in [`../matlab/`](../matlab/) are the current ones: ported to Linux and R2014b, and rebuilt around a single-reader serial model. Keep both - this folder is the record of how the rig was designed, not the code to run today.

## Licensing note

The original repository carried `LICENSE_PENDING.txt`, stating that a licence had to be approved by the lab before publication. If that has not happened yet, keep this repository **private** until it has.

---

*JC Lab, University of Groningen. Questions: Vasilis Kapantaidakis - vaskapant@gmail.com or v.kapantaidakis@student.rug.nl*

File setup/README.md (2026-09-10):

# setup/

Configuration files referenced by the docs.

| File | Install |
|---|---|
| `99-arduino-matlab.rules` | `sudo cp 99-arduino-matlab.rules /etc/udev/rules.d/` then `sudo udevadm control --reload-rules && sudo udevadm trigger` |
| `matlab-2p-experiment.desktop` | `cp *.desktop ~/.local/share/applications/` then `update-desktop-database ~/.local/share/applications` and **log out / back in** |
| `matlab-virmen-design.desktop` | as above |

The two launchers are deliberately separate — see [docs/03-matlab.md](../docs/03-matlab.md).
Running an experiment from the software-GL launcher segfaults MATLAB.

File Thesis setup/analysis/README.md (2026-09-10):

# Analysis scripts

This folder is reserved for analysis code used after acquisition.

## Folder layout

- behavioral: tracking and behavioral response analysis
- calcium_imaging: fluorescence extraction and response analysis
- projection: projection geometry and calibration calculations

## Behavioral analysis

Add scripts used to extract fly position frame by frame and quantify locomotor activity, chamber occupancy, and responses to projected dot stimuli.

## Calcium imaging analysis

Add scripts used to extract fluorescence signals from regions of interest, calculate fluorescence changes relative to baseline, and align responses to black-white stimulus epochs.

## Projection analysis

Add calculations used for conical projection geometry, optical distances, and transformation validation.

Raw videos and imaging files should not be committed here unless a separate data-release plan is approved.

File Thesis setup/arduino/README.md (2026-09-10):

# Arduino synchronization

The Arduino Uno was used only for the two-photon calcium-imaging workflow, not for the freely moving behavioral experiment.

## Frame counter

File: `frame_counter/frame_counter.ino`

Logic:

- TTL input is connected to digital pin 2.
- Each rising edge triggers an interrupt.
- The frame counter is incremented for each detected pulse.
- Serial communication runs at 115200 baud.
- MATLAB receives frame messages in the format `FRAME,<frame number>`.

## Purpose in the two-photon workflow

The Arduino was used to count or relay TTL timing pulses so that MATLAB/ViRMEn stimulus timing could be aligned with two-photon calcium-imaging acquisition.

## Wiring

| Signal | Arduino connection | Purpose |
|---|---|---|
| Imaging/DAQ TTL output | Digital pin 2 | Frame or trigger counting |
| Ground | Arduino GND | Common reference |
| USB serial | USB port | MATLAB communication |
| DAQ/imaging trigger | Add final pin/channel | Two-photon stimulus triggering |

## Not used for behavioral experiment

The freely moving behavioral experiment was camera-based. The Arduino frame counter documented here was not part of that behavioral acquisition workflow.

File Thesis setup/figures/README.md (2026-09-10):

# Figures

Use this folder for approved setup figures and diagrams.

## Recommended figure/photo files

Upload only the images that are useful for documenting the final setup. Use descriptive names rather than phone-camera names.

| Recommended file name | What it should show | Use |
|---|---|---|
| `twophoton_screen_top_view.jpg` | Two-photon conical screen, top view. This corresponds to the first setup photo. | Documents the reduced two-photon screen geometry. |
| `twophoton_screen_large_top_view.jpg` | Two-photon conical screen with the rear-projection surface visible. This corresponds to the second setup photo. | Documents the inserted screen surface before/after replacing the paper with rear-projection film. |
| `twophoton_screen_side_view.jpg` | Two-photon conical screen from the side. This corresponds to the third setup photo. | Documents the conical height and side profile. |
| `fly_on_plate_open_skull.jpg` | Fly positioned on the fly plate with the skull/head capsule open. This corresponds to the fourth setup photo. | Documents the preparation used for two-photon calcium imaging. |
| `twophoton_camera_area_of_interest.jpg` | Two-photon camera view used to locate the imaging area of interest. This corresponds to the fifth setup photo. | Documents how the region of interest was located before imaging. |
| `behavioral_arena_screen_template_midline_1.jpg` | Behavioral arena screen with printed cone template/midline guide. | Documents alignment of the larger behavioral arena screen. |
| `behavioral_arena_screen_template_midline_2.jpg` | Behavioral arena screen with template PDF used to identify the midline. | Documents the template-based centering step. |
| `behavioral_arena_screen_template_midline_3.jpg` | Behavioral arena screen and paper template during assembly/alignment. | Documents the full-size behavioral screen assembly. |
| `behavioral_arena_screen_template_midline_4.jpg` | Behavioral arena screen with full paper template layout. | Documents the larger screen template before final film insertion. |

## Images to keep out of GitHub

Do not upload the filter/spectrum image for now. It was not used in the final setup, so keep it only in local notes unless it becomes relevant for troubleshooting or historical documentation.

## Notes

- The first three photos document the screen used for two-photon microscopy.
- The inner paper/screen surface was later replaced by rear-projection film.
- The fourth photo documents the fly preparation on the plate with the skull/head capsule open.
- The fifth photo documents the two-photon camera view used to locate the imaging area of interest.
- The remaining behavioral-arena photos document the larger behavioral screen with the printed template PDF used for the midline/centering step.

Do not include unpublished data figures here unless the repository is intended to archive analysis results.

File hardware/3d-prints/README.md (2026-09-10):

# 3D printed parts

Optomechanical posts and post holders from the **PLAb: Optical Posts and Post
Holders** system by **Louis Edelman (@LowBoom)**:

  https://www.printables.com/model/1729832-plab-optical-posts-and-post-holders

The published set has 14 files (8 holders, 5 posts, 1 example assembly). Only
the two variants used on this rig are mirrored here.

| File | Part |
|---|---|
| `post_L50_A_M6.step` | optical post, 50 mm, variant A, M6 |
| `holder_w50_h75_lr_M6.step` | post holder, 50x75 mm, left/right, M6 |

Exported from Onshape as STEP AP242.

LICENCE: these are a third-party design. Confirm the terms on the Printables
page permit redistribution and keep the attribution above with any copy. If
they do not, delete these files and link to the source instead.

See ../../docs/07-3d-printed-parts.md

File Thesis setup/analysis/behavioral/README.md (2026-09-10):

# Behavioral analysis

Place behavioral tracking and analysis scripts here.

Expected functions:

- extract fly position frame by frame
- align video frames to Arduino frame counts
- quantify locomotor activity
- quantify chamber occupancy
- quantify responses to projected conspecific-like dot stimuli

Do not commit raw videos unless a separate data-release plan is approved.

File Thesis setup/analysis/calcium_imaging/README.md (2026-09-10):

# Calcium imaging analysis

This folder documents the Excel workbook used as a calcium-imaging analysis example/template.

## File to upload

Upload the existing workbook here:

```text
Results_darktowhite1518.csv.xlsx
```

This is the Excel file generated from the ImageJ/Fiji `Results` table for the dark-to-white two-photon recording. It is not a newly generated workbook; it is the working spreadsheet you used and want to keep in the repository as a template/example for future calcium-imaging analysis.

## Purpose

The workbook shows how ROI fluorescence values exported from ImageJ/Fiji were organized and processed for a dark-to-white calcium-imaging experiment.

It can be used as a template for similar recordings by replacing the raw ImageJ/Fiji results with a new export and adapting the formulas, baseline frames, and stimulus frames as needed.

## Data structure

The workbook contains one sheet:

```text
Results_darktowhite1518
```

The first columns contain the ImageJ/Fiji ROI measurements:

```text
Frame / index
Label
Area1, Mean1, MinThr1, MaxThr1
Area2, Mean2, MinThr2, MaxThr2
Area3, Mean3, MinThr3, MaxThr3
Area4, Mean4, MinThr4, MaxThr4
Area5, Mean5, MinThr5, MaxThr5
```

The workbook therefore supports five ROIs in its current form.

## Analysis columns

Additional columns to the right of the ImageJ/Fiji export contain spreadsheet formulas used to process the ROI fluorescence traces.

In the current file, these formulas include subtraction of one ROI trace from other ROI traces and baseline-normalized percentage-change calculations. For example, some columns calculate differences between ROI mean intensities, and later columns calculate percentage change relative to a baseline value.

## General analysis logic

The spreadsheet follows this general workflow:

1. Export ROI intensity values from ImageJ/Fiji.
2. Keep one row per imaging frame.
3. Use the `Mean` columns as fluorescence traces for each ROI.
4. Use formula columns to calculate corrected or relative fluorescence values.
5. Define a baseline period from the pre-stimulus frames.
6. Calculate response values relative to the baseline.
7. Use the resulting traces or summary values for plotting and statistics.

## Important notes for reuse

- Keep a copy of the original workbook before editing.
- Do not overwrite the original formulas unless you are making a new analysis version.
- When reusing the workbook, replace the ImageJ/Fiji raw results carefully and check that formulas still refer to the correct columns.
- Record the baseline frame range used for each experiment.
- Record the stimulus timing, for example dark-to-white onset frame and offset frame.
- Save each experiment-specific copy with a descriptive file name, such as `Results_darktowhite1518_fly01.xlsx`.

## Missing information to add later

Add the following details once finalized:

- exact baseline frame range
- exact stimulus onset and offset frames
- imaging frame rate
- ROI-selection criteria
- whether any ROI was used as background or reference signal
- final formula definitions for each calculated column

## Data policy

This folder should contain analysis templates, example spreadsheets, and scripts. Raw two-photon imaging files should be stored separately unless a data-release plan is approved.

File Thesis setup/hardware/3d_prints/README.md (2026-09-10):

# 3D-print files

This folder is the single place for all 3D-print files used in the conical visual stimulation setup.

Keep all printable or slicer files here, including STL, 3MF, and OpenSCAD files. The goal is that someone can open this folder and understand what every printed part is for.

## Important screen-file distinction

There are two related conical screen designs:

1. **Full-size screen / behavioral arena screen**: the full-size design. In the uploaded files, this is the version labelled `Full screen Max Planck (Philip)`.
2. **Two-photon screen**: the reduced version used in the two-photon microscope setup. In the uploaded files, this is the version labelled `Full screen 2mm groove sized 0.5 when sliced`, meaning the full-screen design was used at 0.5 scale during slicing.

The two-photon screen is therefore the 0.5-scale file, not the Max Planck full-size file.

## File list and purpose

| Part | Recommended file name | Format | Purpose |
|---|---|---|---|
| Full-size screen / behavioral arena screen | `full_screen_max_planck_philip.stl` | STL | Full-size conical screen design. Uploaded originally as `Full screen Max Planck (Philip).stl`. |
| Full-size screen OpenSCAD design | `full_screen_max_planck_philip.scad` | SCAD | OpenSCAD source file for the full-size screen. Uploaded originally as `Full screen Max Planck (Philip).scad`. |
| Two-photon 0.5-scale screen | `twophoton_screen_0p5_scale_2mm_groove.stl` | STL | Reduced two-photon screen. Uploaded originally as `Full screen 2mm groove sized 0.5 when sliced.stl`. |
| Two-photon 0.5-scale screen OpenSCAD design | `twophoton_screen_0p5_scale_2mm_groove.scad` | SCAD | OpenSCAD source file for the reduced two-photon screen. Uploaded originally as `Full screen 2mm groove sized 0.5 when sliced.scad`. |
| Behavioral full-size conical screen project file | `behavioral_full_screen_2mm_groove.3mf` | 3MF | Slicer/project file for the full-size screen, if used. |
| Two-photon reduced conical screen project file | `twophoton_reduced_screen.3mf` | 3MF | Slicer/project file for the reduced two-photon screen. |
| Conical screen OpenSCAD design | `conical_screen_design.scad` | SCAD | Parametric design file for generating the conical screen and retaining rings. |
| Projector holder | `projector_holder_height_adjustable.stl` | STL | Holds and positions the Texas Instruments DLP3010 LightCrafter projector relative to the mirror and breadboard. |
| Projector holder OpenSCAD design | `projector_holder_height_adjustable.scad` | SCAD | Parametric source file for the projector holder. |
| Projector holder project file | `projector_holder_height_adjustable.3mf` | 3MF | Slicer/project file for the projector holder, if available. |
| Circular screen mounts | `screen_circular_mounts.3mf` | 3MF | Circular mounting parts used to stabilize or position the conical screen. |
| Fly plate | `Flyplate5.stl` | STL | Fly holder/plate component used with the setup. |
| 9 mm ball holder | `ball_9mm_holder_65mm.3mf` | 3MF | Adjustable ball-holder component, 9 mm ball size and 65 mm length. |
| 6 mm ball holder | `ball_6mm_holder_32mm.3mf` | 3MF | Adjustable ball-holder component, 6 mm ball size and 32 mm length. |

## Uploaded file names to keep or rename

The following original file names are acceptable, but the recommended names above are cleaner for long-term use:

```text
Full screen Max Planck (Philip).scad
Full screen Max Planck (Philip).stl
Full screen 2mm groove sized 0.5 when sliced.scad
Full screen 2mm groove sized 0.5 when sliced.stl
Flyplate5.stl
```

## Printing material

The ring used during setup testing was printed from Prusament PLA Prusa Galaxy Black on an Original Prusa XL 5-Toolhead 3D Printer with enclosure.

A matte charcoal-black PLA was considered as an alternative to reduce light reflections from the printed parts.

## Notes

Use descriptive file names and keep older test versions only if they are clearly labelled. For example, use `_old`, `_failed`, or `_prototype` only when the file is useful for documenting the design process.

Do not mix raw experimental data with 3D-print files in this folder.

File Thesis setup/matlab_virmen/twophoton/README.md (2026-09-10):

# Two-photon ViRMEn scripts

This folder contains the final ViRMEn worlds and MATLAB scripts used for the two-photon visual-stimulation workflow.

## Final scripts used in two-photon microscopy

The final two-photon calcium-imaging stimulation used separate black-background and white-background ViRMEn worlds/scripts:

| File | Role |
|---|---|
| `BlackChamber.m` | Final black-background stimulation script. Runs for a fixed duration, logs Arduino TTL frame timing, and ends automatically. |
| `BlackChamber.mat` | Saved ViRMEn world for the black-background condition. Upload manually. |
| `whi.m` | Final white-background stimulation script. |
| `whi.mat` | Saved ViRMEn world for the white-background condition. Upload manually. |

## Protocol used in the thesis

The two-photon visual stimulus consisted of black-background and white-background visual stimulation.

- stimulus control: MATLAB and ViRMEn
- synchronization: Arduino--DAQ interface
- Arduino serial format: `FRAME,<frame number>`
- black condition default duration in `BlackChamber.m`: 5 min, unless overwritten by `protocol.blackDurationSec` in the MATLAB base workspace

Earlier notes refer to 1500 imaging frames per script followed by a 300-frame break. Keep the final values in the master script/protocol file and update this README if the final timing differs.

## Supporting and development files

These files may also be kept in this folder as supporting or earlier ViRMEn worlds/scripts:

- `Behaviorarena.m`
- `Behaviorarena.mat`
- `cilinder.m`
- `cilinder.mat`
- `MasterSwitchByDAQ600.m`
- `MasterSwitchByDAQ600_LoadedWorlds.m`
- `WhiteChamber.m`
- `WhiteChamber.mat`
- `WhiteChamberDots.m`
- `WhiteChamberDots.mat`

## File roles

- `BlackChamber.m` / `BlackChamber.mat`: final black-background two-photon condition.
- `whi.m` / `whi.mat`: final white-background two-photon condition.
- `MasterSwitchByDAQ600_LoadedWorlds.m`: master workflow for loading saved ViRMEn worlds and switching conditions.
- `.mat` files: saved ViRMEn world files.
- `Behaviorarena` and `cilinder` files: arena/world geometry or setup files used during development and stimulation.

## Important local settings

Before running these scripts on another computer, update local paths, serial-port names, saved `.mat` locations, and DAQ/Arduino trigger settings.

## Important note

Do not commit raw two-photon imaging data here. Store raw imaging data separately unless a data-release plan is approved.

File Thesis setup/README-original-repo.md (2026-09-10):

# Conical visual stimulation system for Drosophila experiments

This repository contains the 3D-print files, control scripts, and documentation for a conical visual stimulation setup used for behavioral testing and two-photon calcium imaging in *Drosophila melanogaster*.

The system was developed to present controlled visual stimuli while preserving optical access for two-photon microscopy. It includes a conical rear-projection screen, 3D-printed supports, a folded projector path, Arduino-based synchronization for two-photon calcium imaging, and MATLAB/ViRMEn stimulus control.

## Repository structure

```text
.
├── arduino/
│   └── frame_counter/
├── calibration/
│   ├── cone_template/
│   └── projection_alignment/
├── docs/
├── hardware/
│   └── 3d_prints/
├── matlab_virmen/
│   ├── behavioral/
│   └── twophoton/
├── analysis/
│   ├── behavioral/
│   └── calcium_imaging/
└── figures/
```

## Folder purpose

| Folder | Purpose |
|---|---|
| `hardware/3d_prints/` | One folder containing all STL, 3MF, and OpenSCAD files for printed parts. |
| `arduino/` | Arduino TTL frame-counting and synchronization code used for the two-photon calcium-imaging workflow. |
| `matlab_virmen/` | MATLAB and ViRMEn stimulus-control scripts. |
| `calibration/` | Paper cone template, calibration grid, and projection-alignment documentation. |
| `analysis/` | Behavioral and calcium-imaging analysis documentation/scripts. |
| `docs/` | Thesis appendix, repository manifest, and protocol documentation. |
| `figures/` | Approved setup diagrams and photographs. |

## Hardware overview

The setup uses:

- Texas Instruments DLP3010 LightCrafter projector / DLP3010-based projection system
- rear-projection film mounted in a conical support
- 45° folding mirror
- 3D-printed conical screen supports and mounts
- Arduino Uno Rev3 for TTL frame counting and synchronization during two-photon calcium imaging
- MATLAB R2018a with ViRMEn

## Tested hardware and software environment

The setup was tested using the following hardware and software environment:

| Component | Tested setup |
|---|---|
| Operating system | Microsoft Windows 11 |
| MATLAB | MATLAB R2018a |
| Virtual reality engine | ViRMEn from the Tank Lab GitHub repository: `https://github.com/Tank-Lab/ViRMEn` |
| Arduino board | Arduino Uno Rev3 |
| Arduino software | Arduino IDE, latest installed version at the time of use |
| Projector / DMD | Texas Instruments DLP3010-based projector / DMD system |
| 3D printer | Original Prusa XL 5-Toolhead 3D Printer with enclosure |
| Filament | Prusament PLA Prusa Galaxy Black |
| Printed part confirmed | Current ring / conical support ring |

MATLAB R2018a was used because it is compatible with the ViRMEn workflow used for this setup.

The printed ring currently available for the setup was printed using Prusament PLA Prusa Galaxy Black on an Original Prusa XL 5-Toolhead 3D Printer with enclosure.

The ViRMEn version should be taken from the Tank Lab GitHub repository. For exact long-term reproducibility, record the ViRMEn commit or download date used for a specific experiment when available.

## Conical screen designs

Two related screen designs were used:

1. **Behavioral arena screen**: full-size conical screen with visible diameter 220 mm to 40 mm and height 60 mm.
2. **Two-photon screen**: reduced conical screen with visible diameter 110 mm to 20 mm and height 30 mm.

All 3D-print files should be placed in:

```text
hardware/3d_prints/
```

The README in that folder explains what every printable file is.

## Arduino synchronization

The Arduino frame counter was used for the two-photon calcium-imaging workflow. It listens for TTL pulses on digital pin 2. Each rising edge is counted as one acquired frame and sent to MATLAB over serial at 115200 baud:

```text
FRAME,<frame number>
```

The Arduino was not part of the freely moving behavioral experiment.

## MATLAB and ViRMEn

Two-photon stimulation files are stored in:

```text
matlab_virmen/twophoton/
```

Behavioral files, if added later, should be stored in:

```text
matlab_virmen/behavioral/
```

Before use, update local paths, serial port settings, and saved ViRMEn world locations in the master scripts.

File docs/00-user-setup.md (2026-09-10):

# 00 — User and OS setup

Baseline configuration of the Ubuntu machine before any rig software is installed. Everything below was done on **Ubuntu 24.04.4 LTS**.

Reference machine: `flylab-Dell-Pro-14-PC14250`, user `flylab`.

---

## 1. Check the OS

```bash
lsb_release -d
gcc --version | head -1
```

Expected on the reference machine:

```
Description:	Ubuntu 24.04.4 LTS
gcc (Ubuntu 13.3.0-6ubuntu2~24.04.1) 13.3.0
```

gcc 13 matters later — ViRMEn's 2016-era C code needs a compiler flag to build against it ([04](04-virmen.md)).

## 2. Use an Xorg session, not Wayland

**This is not optional.** FicTrac's GUI is built on older OpenCV/Qt, which fails under Wayland:

```
The Wayland connection experienced a fatal error: Protocol error
```

Check which you are on:

```bash
echo $XDG_SESSION_TYPE
```

If it says `wayland`:

1. Log out.
2. On the login screen, click your username.
3. Click the **gear icon** at the bottom-right of the password field.
4. Select **"Ubuntu on Xorg"**.
5. Log in.

The choice persists for future logins. Re-check:

```bash
echo $XDG_SESSION_TYPE     # want: x11
```

Xorg suits the whole stack anyway — MATLAB R2014b, ViRMEn's GLFW rendering and FicTrac's OpenCV windows are all X11-era software.

## 3. Serial port access — the `dialout` group

The Arduino appears as a serial device owned by group `dialout`. Without membership, both the Arduino IDE and MATLAB fail to open it.

```bash
sudo usermod -aG dialout $USER
```

**Then log out and log back in** — group membership only applies to a new login session. Verify:

```bash
groups | tr ' ' '\n' | grep -x dialout && echo "OK: in dialout"
```

## 4. Folder layout

One real location per thing, no duplicates. MATLAB gets confused by two copies of a function on its path, so this matters.

```
~/Documents/MATLAB/virmen/              ViRMEn install (compiled .mexa64 live here)
~/Documents/MATLAB/virmen/experiments/  experiment .m and .mat files
~/Documents/MATLAB/arduino/             .ino sketch
~/Documents/MATLAB/ExperimentData/      session output folders (created per run)
~/Documents/fictrac-experiments/        FicTrac config + logs
~/fictrac/                              FicTrac source and build
/opt/pylon/                             Basler Pylon SDK
```

Create them:

```bash
mkdir -p ~/Documents/MATLAB/virmen/experiments
mkdir -p ~/Documents/MATLAB/arduino
mkdir -p ~/Documents/MATLAB/ExperimentData
mkdir -p ~/Documents/fictrac-experiments
```

## 5. Desktop launch pad (optional but convenient)

A single Desktop folder of **symlinks** into the real locations. Symlinks, not copies — there is still only one of each file, so nothing shadows anything.

```bash
mkdir -p ~/Desktop/2P-Rig
ln -sfn ~/Documents/MATLAB/virmen/experiments ~/Desktop/2P-Rig/experiments
ln -sfn ~/Documents/MATLAB/virmen             ~/Desktop/2P-Rig/virmen
ln -sfn ~/Documents/MATLAB/arduino            ~/Desktop/2P-Rig/arduino
ln -sfn ~/Documents/MATLAB/ExperimentData     ~/Desktop/2P-Rig/data
ln -sfn ~/fictrac                             ~/Desktop/2P-Rig/fictrac
ls -l ~/Desktop/2P-Rig/
```

**Do not copy ViRMEn to the Desktop.** Its compiled `.mexa64` files and the patches in [04](04-virmen.md) live at the real path; a second copy will be edited by mistake while MATLAB runs the other.

## 6. Useful packages

```bash
sudo apt-get update
sudo apt-get install -y git build-essential cmake pkg-config \
  ethtool network-manager net-tools
```

`ethtool` and `network-manager` are required by Basler's GigE configurator ([01](01-basler-camera.md)); `net-tools` is only for convenience (`arp`), since Ubuntu 24.04 ships `ip` instead.

---

## Checklist before moving on

- [ ] `echo $XDG_SESSION_TYPE` → `x11`
- [ ] `groups | grep dialout` → present
- [ ] Folder layout created
- [ ] Machine rebooted at least once since the `usermod`

Next: [01 — Basler camera](01-basler-camera.md)

---

*JC Lab, University of Groningen. Problems with this guide? Contact Vasilis Kapantaidakis — vaskapant@gmail.com or v.kapantaidakis@student.rug.nl*

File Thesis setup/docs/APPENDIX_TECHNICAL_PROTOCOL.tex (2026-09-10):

\appendix

\section{Technical appendix}

\subsection{Purpose of the technical protocol}

This appendix describes the construction, alignment, and operation of the conical visual stimulation system used for behavioral testing and two-photon calcium imaging. The system was developed to present controlled visual stimuli to \textit{Drosophila melanogaster} while preserving optical access for two-photon microscopy.\\

The appendix contains the engineering details that are too technical for the main Materials and Methods: screen geometry, 3D-printed components, projection-path calculations, optical alignment, spectral filtering, Arduino synchronization, MATLAB/ViRMEn control, and practical setup steps.\\

\subsection{Required components}

\begin{table}[h]
\centering
\small
\begin{tabular}{p{4cm} p{6cm} p{5cm}}
\hline
\textbf{Component} & \textbf{Specification} & \textbf{Purpose} \\
\hline
Projector & Texas Instruments DLP3010 LightCrafter & Visual stimulus projection \\
Projection surface & Rear-projection film & Final conical visual stimulus surface \\
Paper cone template & A4 printed truncated-cone template & Initial screen centering and fit check \\
Folding mirror & Planar mirror, approximately 50~$\times$~70~mm clear aperture & Redirects projector beam upward \\
3D-printed screen support & PLA conical support and retaining rings & Holds projection film in conical geometry \\
3D-printed projector holder & Adjustable projector holder & Positions projector relative to mirror and breadboard \\
Circular mounts & 3D-printed screen mounting rings/supports & Stabilize conical screen \\
Ball holders & 9~mm ball holder, 65~mm; 6~mm ball holder, 32~mm & Adjustable positioning of mounted components \\
Bandpass filter & 374/50~nm filter & Restricts projected stimulus spectrum \\
Arduino & Arduino Uno & Trigger detection and frame counting \\
DAQ interface & Microscope DAQ system & Imaging/stimulus synchronization \\
Computer & MATLAB 2018a with ViRMEn & Stimulus generation and experiment control \\
Optical breadboard & Microscope breadboard & Mechanical reference plane \\
Fly holder & Custom holder & Stabilizes tethered fly for imaging \\
\hline
\end{tabular}
\caption{Main components used to build and operate the conical visual stimulation system.}
\label{tab:appendix_components}
\end{table}

\subsection{Conical screen design}

\subsubsection{Behavioral arena screen}

The behavioral arena used the full-size conical screen design. The visible projection surface was a truncated cone with a large diameter of 220~mm, a small diameter of 40~mm, and a vertical height of 60~mm. The corresponding radii were 110~mm and 20~mm.\\

The cone wall angle relative to the vertical axis was calculated from the radial difference and vertical height:\\

\[
\theta = \tan^{-1}\left(\frac{110 - 20}{60}\right) = \tan^{-1}(1.5) = 56.3^\circ
\]

The complementary groove angle relative to the horizontal ring plane was:\\

\[
\phi = 90^\circ - 56.3^\circ = 33.7^\circ
\]

The retaining grooves were therefore designed with an angle of approximately 33.7$^\circ$ relative to the ring plane. In practice, a groove angle of approximately 34$^\circ$ can be used to simplify manufacturing and allow tolerance for film insertion.\\

The full-size behavioral arena STL used a 2~mm retaining groove and had an approximate external bounding box of 240~$\times$~240~$\times$~80~mm. This STL corresponds to the behavioral arena screen, not to the two-photon screen.\\

\subsubsection{Two-photon conical screen}

The two-photon conical screen was a reduced version of the behavioral arena design. It preserved the same conical design principle but used smaller dimensions to fit within the microscope workspace.\\

The final two-photon projection surface had a large visible diameter of 110~mm, a small visible diameter of 20~mm, and a vertical height of 30~mm. The top of the visible screen was positioned 250~mm above the optical breadboard, placing the bottom of the visible screen at 218~mm and the midpoint of the conical projection surface at 234~mm above the breadboard.\\

\subsubsection{A4 paper cone template}

Before mounting the rear-projection film, an A4 paper cone template was used to check the conical screen geometry and centering. The template was generated using the Templatemaker truncated-cone tool with bottom diameter = 110~mm, top diameter = 20~mm, height = 30~mm, page preset = A4, and units = mm.\\

The printed paper template was inserted into the screen support to verify that the screen was centered and that the conical geometry matched the intended dimensions. After this check, the paper template was removed and the rear-projection film was mounted in the retaining grooves.\\

The exact exported PDF template and printed scale used during the experiment should be uploaded to the GitHub repository.\\

\subsection{3D printing and assembly}

\subsubsection{Printing material and printer}

The conical screen components and mounting parts were fabricated by fused deposition modelling. The ring used during setup testing was printed from Prusament PLA Prusa Galaxy Black filament on an Original Prusa XL 5-Toolhead 3D Printer with enclosure.\\

Black PLA was selected to reduce unwanted reflections from the support structure during visual stimulation. A more matte charcoal-black PLA filament, Polymaker Panchroma Matte PLA, was considered as an alternative material to further reduce surface reflectivity. Unless otherwise stated, the printed ring used in the setup was made from Prusament PLA Prusa Galaxy Black.\\

\subsubsection{Screen support and projection-film assembly}

The screen support was designed in OpenSCAD. The design contained upper and lower retaining rings with angled grooves matched to the cone wall angle. This allowed the projection film to follow the conical surface rather than being forced into a vertical slot.\\

Water-soluble support material was used where required to preserve the angled groove geometry during printing. After printing, the support material was removed and the groove surfaces were inspected. The A4 paper cone template was then used to confirm fit and centering before final film mounting.\\

After the paper-template check, the rear-projection film was cut to fit the conical surface and inserted into the upper and lower grooves. The film was mounted under light tension to reduce wrinkles while preserving the intended conical geometry.\\

\subsubsection{Projector holder}

A custom 3D-printed projector holder was designed in OpenSCAD to position the Texas Instruments DLP3010 LightCrafter projector relative to the optical breadboard and folding mirror. The holder aligned with the M6-hole grid of the support system and allowed adjustment of the projector beam height.\\

The projector holder STL had an approximate external bounding box of 75.2~$\times$~116.0~$\times$~80.0~mm. The OpenSCAD design used a projector width of 73.2~mm, a projector depth of 73.2~mm, and a thicker projector section of 75.2~mm. The holder plate height was 80~mm, with a 5~mm holder thickness and a 7~mm base plate.\\

The holder included M6-compatible mounting grooves. The M6 groove width was 6.3~mm, the groove length was 50~mm, and the grid spacing was 25~mm. The support wall thickness was 4~mm and the support height was 10~mm.\\

\subsubsection{Circular mounts and ball holders}

Additional 3D-printed mounting parts were used to position and stabilize the projection system. These included circular mounts for the conical screen and ball-joint holders for adjustable positioning.\\

The design files included a 9~mm ball holder with a 65~mm length and a 6~mm ball holder with a 32~mm length. These components were used for mechanical adjustment and stabilization during setup alignment.\\

\subsection{Projection-path geometry}

\subsubsection{Folded optical path}

A folded projection path was used to fit the projector into the restricted space around the two-photon microscope. The projector beam travelled horizontally from the projector lens to a planar mirror mounted at approximately 45$^\circ$. The mirror reflected the beam vertically upward onto the conical rear-projection screen.\\

The relevant optical constraint is the total folded path length:\\

\[
L = x + y
\]

where $x$ is the horizontal distance from the projector beam exit to the mirror center, and $y$ is the vertical distance from the mirror center to the screen mid-height.\\

\subsubsection{Full-size screen optical calculation}

For the full-size behavioral arena screen, the maximum screen diameter was 220~mm. Assuming a projector throw ratio of $T=1.2$, the total folded optical path was:\\

\[
L = T D_{\max} = 1.2 \times 220 = 264~\mathrm{mm}
\]

Thus:\\

\[
x + y = 264~\mathrm{mm}
\]

A balanced practical split was:\\

\[
x \approx 130~\mathrm{mm}, \quad y \approx 134~\mathrm{mm}
\]

where $x$ is the projector-to-mirror distance and $y$ is the mirror-to-screen-midpoint distance.\\

\subsubsection{Two-photon screen projection geometry}

For the reduced two-photon screen, the projection path was adjusted to fit the microscope workspace. In the final configuration, the center of the projector beam and the mirror center were positioned 120~mm above the optical breadboard. The midpoint of the conical projection surface was positioned 234~mm above the breadboard, giving a vertical mirror-to-screen-midpoint distance of 114~mm.\\

The lens-to-mirror distance was kept at approximately 35--40~mm to reduce beam clipping at the mirror. A mirror with an approximate clear aperture of 50~$\times$~70~mm was used.\\

\subsection{Optical alignment}

\subsubsection{Paper-template check}

Before the rear-projection film was mounted, the printed A4 paper cone template was inserted into the screen support to check the fit and centering of the conical geometry. If the template did not sit symmetrically, the screen support was re-seated and checked for obstruction before mounting the final projection film.\\

\subsubsection{Calibration image}

A calibration image containing concentric circles, radial spokes, and orthogonal crosshairs was used for projector, mirror, and screen alignment. The calibration image was projected within a square active projection region to avoid distortions caused by the native rectangular projector raster.\\

\subsubsection{Mechanical alignment}

Mechanical alignment was performed before applying software offsets. During this step, all lateral and anteroposterior software offsets were set to zero. The projector, mirror, and cone were adjusted until the projected circles were centered on the screen, the radial spokes were evenly distributed, and the projected rings appeared symmetric.\\

Software offsets were not used to compensate for large mechanical misalignment. If large offsets were required, the projector, mirror, or cone position was corrected physically.\\

\subsection{Spectral filtering}

A 374/50~nm bandpass filter was placed in the projection path during two-photon imaging experiments. The filter restricted the projected stimulus spectrum to reduce contamination of the fluorescence detection pathway by projector light.\\

\subsection{MATLAB and ViRMEn workflow}

\subsubsection{Software environment}

Visual stimuli were generated and controlled using MATLAB 2018a and ViRMEn. ViRMEn was used as the virtual-reality stimulus engine, based on the Tank-Lab/ViRMEn GitHub repository. MATLAB initialized the experiment, controlled communication with the Arduino or DAQ interface, launched the ViRMEn environment, applied projection correction, and saved timing information.\\

\subsubsection{Conical projection correction}

Because the projection surface was conical, stimulus coordinates were transformed before display. The transformation mapped virtual stimulus coordinates to projector coordinates to reduce geometric distortion on the physical screen.\\

The transformation used the scaling relation:\\

\[
s = \frac{1}{\alpha r + \beta z}
\]

with:\\

\[
\alpha = 1.7, \quad \beta = -1.2
\]

where $r = \sqrt{x^2 + y^2}$. The normalized displayed radius was:\\

\[
\rho = rs = \frac{r}{\alpha r + \beta z}
\]

The transformation-implied cone angle was approximately 59.7$^\circ$, close to the physical cone angle of 56.3$^\circ$. Empirical lateral and anteroposterior shifts were used only for final calibration after mechanical alignment.\\

\subsubsection{Two-photon black-white stimulus}

For two-photon imaging, visual stimulation consisted of alternating black and white stimulus epochs. Each stimulus script lasted 1500 imaging frames and was followed by a 300-frame break period before the next script was presented. Stimulus timing was controlled in MATLAB/ViRMEn and synchronized with imaging acquisition through the Arduino--DAQ interface.\\

\subsubsection{Behavioral white-chamber dots stimulus}

For behavioral testing, the WhiteChamberDots script was used to project moving dot stimuli representing conspecific-like visual objects. The stimulus was presented in the white-chamber configuration.\\

\subsection{Arduino synchronization and frame counting}

For behavioral experiments, camera frame timing was monitored using TTL pulses detected by an Arduino Uno. The camera TTL output was connected to digital pin~2. Each rising TTL edge triggered an interrupt and was counted as one acquired frame. Frame counts were transmitted to MATLAB through serial communication at 115200 baud.\\

For two-photon imaging, the Arduino--DAQ interface was used to link imaging acquisition with visual-stimulus timing. The imaging acquisition system generated a timing signal that was detected by the Arduino or DAQ interface and used to initiate the MATLAB/ViRMEn stimulus protocol.\\

\subsection{Behavioral MATLAB/ViRMEn implementation}

The WhiteChamber and WhiteChamberDots scripts were implemented as ViRMEn experiments with initialization, runtime, and termination functions. During initialization, the frame threshold was set to 600 frames, the Arduino serial connection was loaded from the shared MATLAB base workspace variable, and timing variables were initialized.\\

During runtime, the scripts read serial messages from the Arduino. Messages were parsed when they matched the format \texttt{FRAME,<frame number>}. The first valid Arduino frame was stored as the start frame. Subsequent frame numbers were logged together with elapsed time and clock time.\\

The scripts terminated automatically when the number of new Arduino frames reached the threshold:\\

\[
\mathrm{lastArduinoFrame} - \mathrm{startFrame} \geq 600
\]

The MasterSwitchByDAQ600\_LoadedWorlds script controlled the behavioral workflow by loading the required ViRMEn worlds, communicating with the Arduino serial connection, and switching between experimental conditions based on the frame-threshold logic.\\

\subsection{Practical setup checklist}

\subsubsection{Two-photon stimulation checklist}

\begin{enumerate}
    \item Confirm that the conical screen is clean and mounted securely.
    \item Insert the printed A4 paper cone template to confirm centering and fit.
    \item Remove the paper template and mount the rear-projection film.
    \item Confirm that the rear-projection film is seated correctly in the retaining grooves.
    \item Switch on the projector.
    \item Insert the 374/50~nm bandpass filter.
    \item Project the calibration image.
    \item Set software offsets to zero.
    \item Mechanically align the projector, mirror, and cone.
    \item Confirm that projected rings and radial spokes are centered and symmetric.
    \item Connect the Arduino and DAQ interface.
    \item Open MATLAB 2018a.
    \item Load the correct ViRMEn environment.
    \item Confirm the correct serial port and output directory.
    \item Start imaging acquisition.
    \item Confirm that the stimulus triggers correctly.
\end{enumerate}

\subsubsection{Behavioral stimulation checklist}

\begin{enumerate}
    \item Confirm that the behavioral arena is clean.
    \item Confirm that the camera is focused on the walking surface.
    \item Connect the camera TTL output to Arduino digital pin~2.
    \item Connect Arduino GND to the camera or DAQ ground.
    \item Connect the Arduino to the computer by USB.
    \item Open MATLAB 2018a.
    \item Load the behavioral master script.
    \item Confirm serial communication at 115200 baud.
    \item Load the WhiteChamberDots script.
    \item Transfer one fly into the arena.
    \item Start acquisition.
    \item Confirm that frame counts are received in MATLAB.
\end{enumerate}

\subsection{Troubleshooting}

If the paper cone template did not sit symmetrically inside the screen support, the screen was re-seated and checked for mechanical obstruction before mounting the rear-projection film.\\

If the projected image was off-center, mechanical alignment was corrected before applying software offsets. Large software offsets indicated that the projector, mirror, or cone required physical realignment.\\

If the projected image was clipped at the mirror, the lens-to-mirror distance was reduced or the mirror position was adjusted.\\

If the visual stimulus did not start with imaging acquisition, the DAQ trigger line, Arduino input, MATLAB serial connection, and ViRMEn script selection were checked.\\

If MATLAB did not receive frame counts, the Arduino serial monitor was used to confirm that TTL pulses were detected. The camera TTL output, Arduino digital pin~2, and common ground connection were checked.\\

If fluorescence recordings showed projector contamination, the position and orientation of the 374/50~nm filter were checked and projector intensity was reduced if necessary.\\

If the projection film was wrinkled, the film was removed and reinserted into the retaining grooves under light tension. The grooves were checked for residual support material or print defects.\\

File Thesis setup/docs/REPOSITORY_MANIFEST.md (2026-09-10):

# Repository manifest

This repository archives the files required to reproduce the conical visual stimulation setup used for behavioral testing and two-photon calcium imaging.

## Core folders

| Folder | Contents |
|---|---|
| `hardware/3d_prints/` | All STL, 3MF, and OpenSCAD files for printed parts, with one README explaining each part. |
| `arduino/` | Arduino TTL frame-counting and synchronization code used for the two-photon calcium-imaging workflow. |
| `matlab_virmen/` | MATLAB and ViRMEn stimulus-control scripts. |
| `calibration/` | Paper cone template, calibration grid, projection-analysis PDF, and alignment documentation. |
| `analysis/` | Post-acquisition behavioral and calcium-imaging analysis documentation/scripts. |
| `docs/` | Thesis appendix and repository documentation. |
| `figures/` | Approved setup diagrams and photographs. |

## Files already added

- `README.md`
- `.gitignore`
- `LICENSE_PENDING.txt`
- `arduino/README.md`
- `arduino/frame_counter/frame_counter.ino`
- `matlab_virmen/README.md`
- `matlab_virmen/twophoton/README.md`
- `matlab_virmen/behavioral/WhiteChamber.m`
- `matlab_virmen/behavioral/WhiteChamberDots.m`
- `matlab_virmen/behavioral/MasterSwitchByDAQ600_LoadedWorlds_NOTES.md`
- `hardware/3d_prints/README.md`
- `calibration/cone_template/README.md`
- `calibration/projection_alignment/README.md`
- `analysis/README.md`
- `analysis/behavioral/README.md`
- `analysis/calcium_imaging/README.md`
- `figures/README.md`
- `docs/APPENDIX_TECHNICAL_PROTOCOL.tex`

## Files still to upload manually

Upload all 3D-print files into `hardware/3d_prints/`:

- full-size behavioral screen STL and 3MF files
- reduced two-photon screen STL and 3MF files
- conical screen OpenSCAD file
- projector-holder STL, 3MF, and OpenSCAD files
- circular screen mount files
- 6 mm and 9 mm ball-holder 3MF files

Upload calibration and experiment files into the relevant folders:

- exact A4 cone-template PDF used for centering
- calibration grid image
- projection-analysis PDF in `calibration/projection_alignment/`
- saved ViRMEn `.mat` world files
- finalized analysis scripts

## Data policy

Raw videos, raw two-photon imaging files, and large experimental datasets should not be committed to this repository unless a separate data-release plan is approved.

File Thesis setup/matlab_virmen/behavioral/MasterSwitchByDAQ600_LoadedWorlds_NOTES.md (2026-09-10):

# MasterSwitchByDAQ600_LoadedWorlds

The master script controls the behavioral ViRMEn workflow.

## Function

It performs the following steps:

1. Opens MATLAB and ViRMEn.
2. Adds the ViRMEn root directory and experiment directory to the MATLAB path.
3. Opens a shared Arduino serial connection.
4. Loads the saved WhiteChamber ViRMEn experiment.
5. Runs WhiteChamber until it terminates after 600 Arduino TTL pulses.
6. Checks that WhiteChamber ended by frame threshold.
7. Loads the saved WhiteChamberDots ViRMEn experiment.
8. Runs WhiteChamberDots until it terminates after 600 Arduino TTL pulses.
9. Saves timing information to the MATLAB base workspace.

## Local settings to update

The original script contained local computer paths and serial-port settings. Before reuse, update:

- ViRMEn root directory
- experiments directory
- serial port name
- baud rate, normally 115200
- saved WhiteChamber.mat path
- saved WhiteChamberDots.mat path

## Required companion files

- WhiteChamber.m
- WhiteChamberDots.m
- WhiteChamber.mat
- WhiteChamberDots.mat
- Arduino frame counter sketch

The full original script can be added here after checking local paths and personal computer identifiers.

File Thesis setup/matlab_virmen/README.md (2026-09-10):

# MATLAB and ViRMEn files

Visual stimuli were generated and controlled using MATLAB 2018a and ViRMEn.

ViRMEn source: Tank-Lab/ViRMEn.

## Two-photon scripts

`twophoton/` contains the ViRMEn worlds and MATLAB scripts used for the two-photon visual-stimulation workflow.

Uploaded files that belong in `twophoton/`:

- `Behaviorarena.m`
- `Behaviorarena.mat`
- `cilinder.m`
- `cilinder.mat`
- `MasterSwitchByDAQ600.m`
- `MasterSwitchByDAQ600_LoadedWorlds.m`
- `whi.m`
- `whi.mat`
- `WhiteChamber.m`
- `WhiteChamber.mat`
- `WhiteChamberDots.m`
- `WhiteChamberDots.mat`

The final two-photon protocol used black and white visual stimulation. Each stimulus script lasted 1500 imaging frames followed by a 300-frame break.

## Behavioral scripts

Use `behavioral/` only for scripts that were specifically used for freely moving behavioral testing outside the two-photon setup.

## Important local settings

Before running on another computer, update local settings in the master scripts:

- ViRMEn root directory
- experiment directory
- serial port name
- saved ViRMEn `.mat` experiment file locations
- DAQ or Arduino trigger channel, if used

## Notes

Do not commit raw two-photon imaging data or behavioral videos here. Store raw data separately unless a data-release plan is approved.

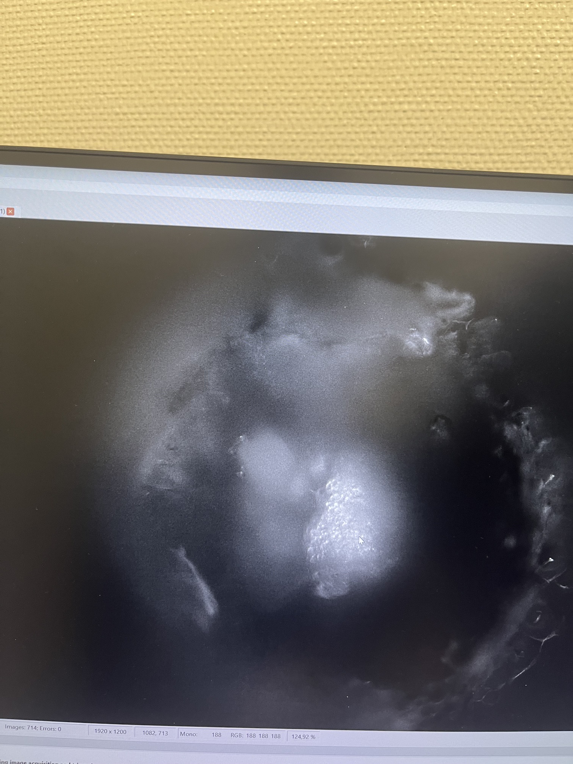
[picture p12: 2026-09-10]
Thesis setup/figures/twophoton_camera_area_of_interest.jpeg

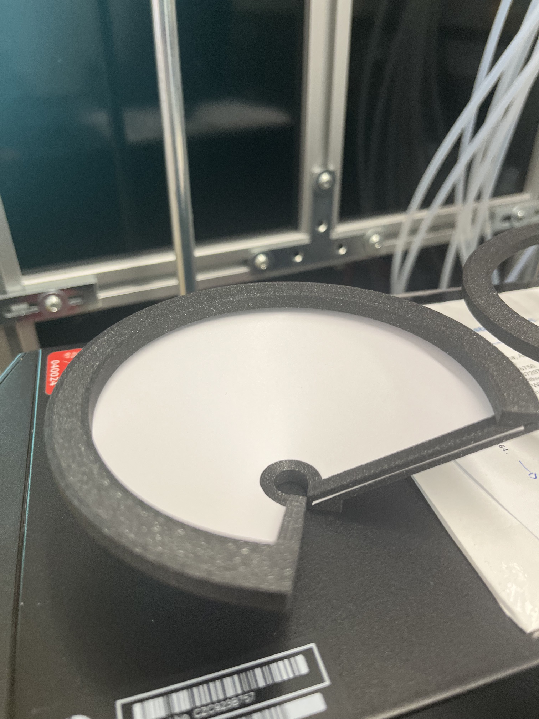
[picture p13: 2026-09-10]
Thesis setup/figures/behavioral_arena_screen_template_midline_4.jpeg

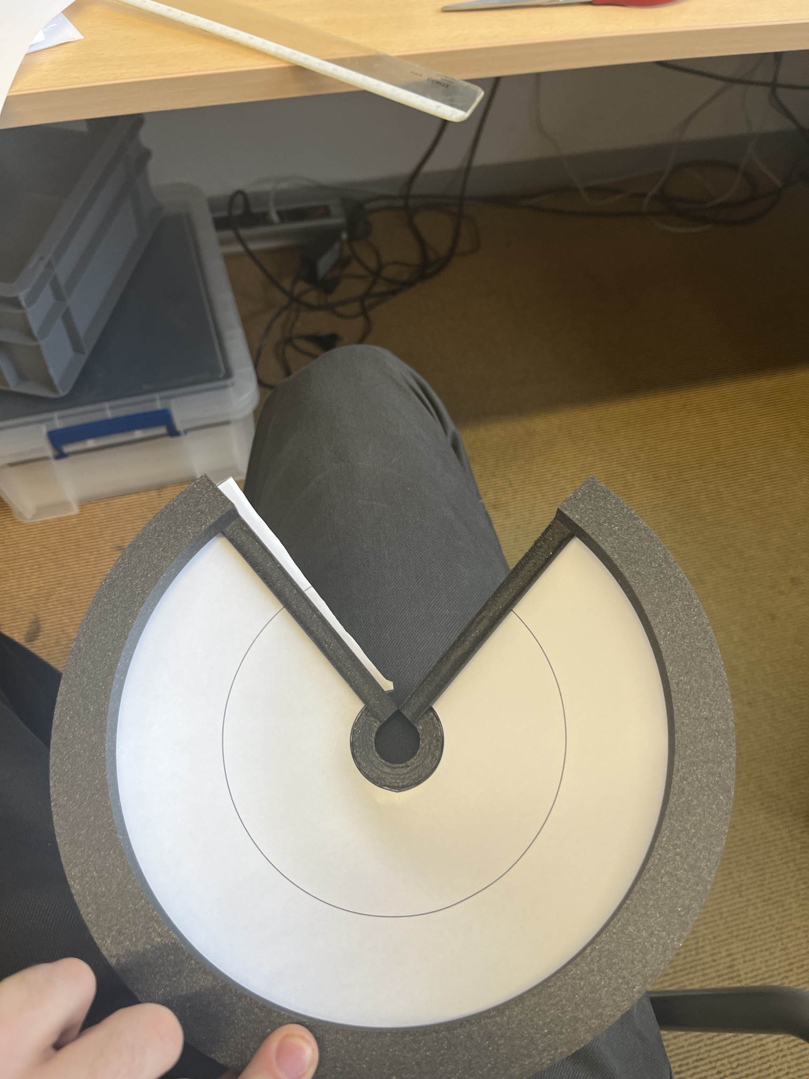
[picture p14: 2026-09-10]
Thesis setup/figures/behavioral_arena_screen_template_midline_2.jpeg

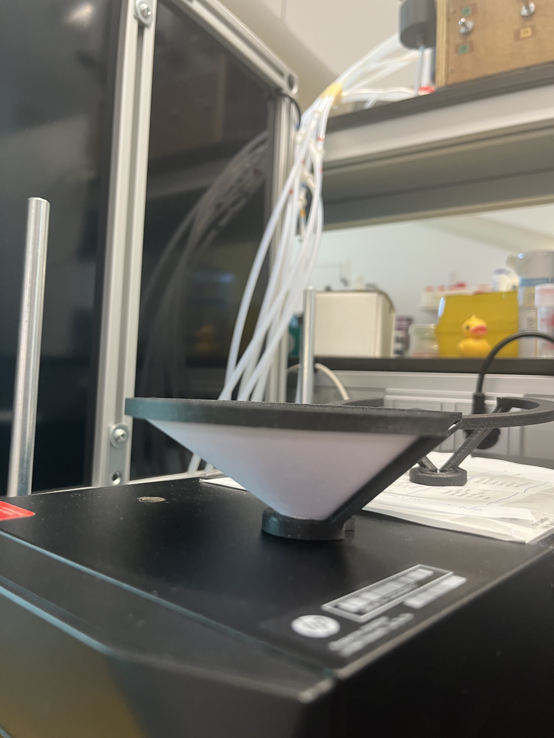
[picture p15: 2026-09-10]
Thesis setup/figures/behavioral_arena_screen_template_midline_1.jpeg

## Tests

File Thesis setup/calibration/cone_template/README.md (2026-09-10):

# Cone template

This folder contains the paper cone templates generated with Templatemaker.nl and used to check the screen midline/centering before inserting the rear-projection film.

## Templatemaker source

Use the cone/frustum template generator:

```text
https://www.templatemaker.nl/en/cone/
```

Set the page preset to A4 and the units to mm unless a different print setup is documented.

## Small screen template: two-photon screen

Use these values in Templatemaker.nl for the small screen used in the two-photon microscope setup:

```text
BOTTOM = 113 mm
TOP = 17 mm
H = 32 mm
PAGEPRESET = A4
UNITS = mm
```

Equivalent URL format:

```text
https://www.templatemaker.nl/en/cone/?BOTTOM=113&TOP=17&H=32&PAGEPRESET=A4&UNITS=mm
```

This template was used to make the paper insert for checking the midline/centering of the small two-photon screen. The inside paper/screen was later replaced by rear-projection film.

## Big screen template: behavioral arena screen

Use these values in Templatemaker.nl for the big screen used in the behavioral arena:

```text
BOTTOM = 226 mm
TOP = 34 mm
H = 64 mm
PAGEPRESET = A4
UNITS = mm
```

Equivalent URL format:

```text
https://www.templatemaker.nl/en/cone/?BOTTOM=226&TOP=34&H=64&PAGEPRESET=A4&UNITS=mm
```

This template was used to generate the paper guide for the big behavioral-arena screen and to identify/check the midline.

## Notes

- Earlier draft values were 110 mm, 20 mm, and 30 mm for the small screen. The updated values above are the ones to insert into Templatemaker.nl for the paper midline templates.
- Upload the exact exported PDF files once available.
- Record the final print settings, especially whether the PDF was printed at actual size/100% scale.

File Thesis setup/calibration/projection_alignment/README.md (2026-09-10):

# Projection alignment

Use this folder for files related to projector, mirror, and conical-screen alignment.

Add:

- calibration grid image
- projection-analysis PDF
- alignment photos or notes, if approved

The calibration grid should contain concentric circles, radial spokes, and crosshairs.

The projector, mirror, and cone should be mechanically aligned first. Software offsets should only be used for small residual errors.

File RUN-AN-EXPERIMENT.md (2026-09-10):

# How to run an experiment

The day-to-day checklist. Follow it top to bottom. Assumes the rig is already installed — if not, start at [docs/00-user-setup.md](docs/00-user-setup.md).

**Problems? Contact Vasilis Kapantaidakis — vaskapant@gmail.com or v.kapantaidakis@student.rug.nl**

---

## Before you start

- [ ] Camera powered and Ethernet connected
- [ ] Arduino plugged in via USB
- [ ] Projector on
- [ ] Ball and air supply on
- [ ] **Arduino IDE Serial Monitor CLOSED** (it blocks MATLAB from the port)
- [ ] **Pylon Viewer CLOSED** (it blocks FicTrac from the camera)

---

## Step 1 — Open a terminal and check the hardware

```bash
ping -c 2 192.168.4.3
ls -l /dev/ttyS101
```

**Good:** ping replies, and `/dev/ttyS101` exists.

If the ping fails → camera is off or unplugged.
If `/dev/ttyS101` is missing → run `sudo ln -sf /dev/ttyACM0 /dev/ttyS101`.

---

## Step 2 — Calibrate FicTrac *(only if the camera moved)*

Skip this if nobody touched the camera since the last session.

```bash
cd ~/Documents/fictrac-experiments
source /opt/pylon/bin/pylon-setup-env.sh /opt/pylon
~/fictrac/bin/configGui config.txt
```

Answer the prompts **one at a time** (do not type ahead):

- "keep the existing sphere ROI?" → **n** (to redraw it)
- "keep the existing ignore regions?" → **n**
- "keep the existing transform?" → **n**

Drawing the ball circle:

- Click **6–8 single points** around the edge of the ball (like clock positions 12, 2, 4, 6, 8, 10)
- **Do not drag** — single clicks only
- Right-click undoes the last point
- **Click on the image window first**, then press **ENTER** to accept

Check the result:

```bash
xdg-open ~/Documents/fictrac-experiments/fictrac-configImg.png
```

The red circle must sit on the edge of the ball. If not, run `configGui` again.

---

## Step 3 — Start FicTrac

```bash
cd ~/Documents/fictrac-experiments
source /opt/pylon/bin/pylon-setup-env.sh /opt/pylon
~/fictrac/bin/fictrac config.txt
```

A window opens showing the ball with tracking overlay, and numbers scroll in the terminal.

**Test it:** spin the ball by hand. The numbers should change sensibly.

**Leave this running.** Use a different terminal for anything else.

To stop later: click the FicTrac window and press **ESC**.

---

## Step 4 — Open MATLAB

Click the **"MATLAB 2P EXPERIMENT (hardware GL)"** icon in the applications menu.

> ⚠️ **Not** the "ViRMEn DESIGN" icon. That one crashes when an experiment runs.
> DESIGN is only for building worlds.

---

## Step 5 — Clean start in MATLAB

Paste this into the MATLAB Command Window every time, before running:

```matlab
close all force
clear global guifig
clear all
clear functions
instrreset
```

This clears leftovers from any previous run. Skipping it causes strange errors.

---

## Step 6 — Run the experiment

```matlab
MasterSwitchByDAQ_WhiteBack_BlackChamber
```

---

## Step 7 — Fill in the fly details

The Command Window asks for these one at a time. Type the answer, press Enter:

```
Experimenter name        :
Fly strain / genotype    :
Fly age (days)           :
Sex (M/F)                :
Experiment name          :
Notes (optional)         :
```

This creates the data folder and saves a metadata file with the session.

---

## Step 8 — Wait for the script to arm

ViRMEn opens and the Arduino connects. You will see:

```
Master script is armed.
Waiting for first DAQ/Arduino frame pulse on /dev/ttyS101 ...
```

---

## Step 9 — Start the two-photon scan

**Now start the 2P.** The first frame trigger starts the experiment automatically.

You will see:

```
First DAQ pulse received.
=== Running WhiteBack ===
```

---

## Step 10 — Watch it run

- The **VR window** shows the world the fly sees
- The **live panel** shows frames, rate, dropped frames, temperature
- The **Command Window** prints a line as frames arrive

The white world runs for its set number of frames, then switches automatically to the black world.

**To stop early:** press **ESC** in the ViRMEn window, or **Ctrl+C** in MATLAB.

---

## Step 11 — When it finishes

It saves the data and opens a summary plot by itself. Check the table it prints:

```
phase              frames    dur (s)  rate (Hz)    dt mean      dt sd
WhiteBack             600      20.01      29.98     33.355      0.412
BlackChamber          600      20.02      29.97     33.362      0.395

Frames lost in transit (sequence gaps): 0
```

**These two numbers must be 0:**

- `Frames lost in transit` — if not 0, the serial link dropped data
- `Missed by sketch` — if not 0, triggers came faster than the Arduino could send

If either is non-zero, the session's frame alignment is unreliable.

---

## Step 12 — Find your data

```
~/Documents/MATLAB/ExperimentData/<date>/<yourname>_<strain>_<experiment>_<time>/
```

Inside:

| File | What it is |
|---|---|
| `metadata.txt` | the fly details you typed |
| `*_allframes.csv` | every frame, all phases |
| `*_WhiteBack.csv` | white phase only |
| `*_BlackChamber.csv` | black phase only |
| `*_sync.csv` | Arduino clock vs MATLAB clock — use this to align with imaging |

To re-plot a session later:

```matlab
plotSession                     % most recent
plotSession('/path/to/folder')  % a specific one
```

---

## Running another fly

1. Press **ESC** in the ViRMEn window if it is still open
2. Run the clean-start block from **Step 5** again
3. Go from **Step 6**

You do **not** need to redo the FicTrac calibration unless the camera moved.

---

## If something goes wrong

| What you see | Do this |
|---|---|
| `Port /dev/ttyS101 is not available` | `sudo ln -sf /dev/ttyACM0 /dev/ttyS101`, then `instrreset` in MATLAB |
| `The device is controlled by another application` | Close Pylon Viewer / other FicTrac. Wait 8 seconds. Try again |
| MATLAB crashes when the world loads | You used the DESIGN icon. Use **2P EXPERIMENT** |
| `guidata ... H must be the handle` | Run the Step 5 clean-start block |
| Nothing happens after "armed" | The 2P is not sending triggers. Check it is scanning and the BNC reaches Arduino pin D2 |
| ViRMEn design panels are blank | Normal in the EXPERIMENT launcher. Use DESIGN only for editing worlds |

Full list: [docs/99-troubleshooting.md](docs/99-troubleshooting.md)

---

**Still stuck? Contact Vasilis Kapantaidakis — vaskapant@gmail.com or v.kapantaidakis@student.rug.nl**

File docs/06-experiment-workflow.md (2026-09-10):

# 06 — Experiment workflow

Running the **WhiteBack → BlackChamber** protocol: two visual worlds shown in sequence, switched on two-photon frame count, with every frame timestamped and logged.

Prerequisites: [00](00-user-setup.md)–[05](05-arduino-daq.md) complete.

---

## The protocol

1. Ask for experiment metadata (Command Window).
2. Open ViRMEn.
3. Open the Arduino via `arduinoFrameLog` (single reader).
4. **Wait for the first DAQ/2P frame pulse** — the script can be armed before the scan starts.
5. Load the **WhiteBack** world, run it until its frame threshold.
6. Switch to the **BlackChamber** world, run it likewise.
7. Save per-phase CSV logs and plot the session.

The movement function is `moveWithKeyboard` — **the fly does not drive the world in this protocol**. World switching is driven purely by 2P frame count. FicTrac, if running, records ball motion alongside.

## Files

| File | Role |
|---|---|
| [`MasterSwitchByDAQ_WhiteBack_BlackChamber.m`](../matlab/MasterSwitchByDAQ_WhiteBack_BlackChamber.m) | the script you run |
| [`WhiteBack.m`](../matlab/WhiteBack.m) / [`BlackChamber.m`](../matlab/BlackChamber.m) | phase logic (end after N frames) |
| `WhiteBack.mat` / `BlackChamber.mat` | the visual worlds |
| [`arduinoFrameLog.m`](../matlab/arduinoFrameLog.m) | serial reader, logger, live panel |
| [`plotSession.m`](../matlab/plotSession.m) | post-hoc plots and summary |

Install all of them into `~/Documents/MATLAB/virmen/experiments/`.

## Configuration block

At the top of the master script:

```matlab
SERIAL_PORT       = '/dev/ttyS101';   % symlink to /dev/ttyACM0 (see doc 05)
baudRate          = 115200;

SHOW_LIVE_MONITOR = true;   % live DAQ panel during the run
MONITOR_EVERY     = 10;     % panel refresh every N frames
AUTO_PLOT_AT_END  = true;   % plot the session when finished
PRINT_EVERY       = 50;     % console line every N frames (0 = off; 1 = every frame)

FULLSCREEN_VR     = false;  % true once the projector is a second display
VR_MONITOR        = 1;      % 1 = primary/laptop, 2 = projector
VR_WIN_W          = 900;    % windowed geometry (when FULLSCREEN_VR = false)
VR_WIN_H          = 700;
VR_WIN_LEFT       = 950;
VR_WIN_BOTTOM     = 300;
```

Frames per phase live in the phase files — `vr.frameThreshold` in `WhiteBack.m` and `BlackChamber.m`.

### Single screen vs projector

**Testing on one screen:** `FULLSCREEN_VR = false`. A windowed VR view sits beside the live monitor panel. With fullscreen on a single display, the VR window covers everything including the panel.

**With the projector**, extend the desktop rather than mirroring:

```bash
xrandr --listmonitors
xrandr | grep -E " connected"
xrandr --output <PROJECTOR> --auto --right-of <LAPTOP>
```

then set `FULLSCREEN_VR = true; VR_MONITOR = 2;`. The fly gets the projector fullscreen; the laptop screen keeps MATLAB and the monitor panel. You do not want your desktop and mouse pointer projected at the animal between trials.

## Running a session

Launch from the **MATLAB 2P EXPERIMENT (hardware GL)** icon — **not** the design one, which segfaults on Run ([03](03-matlab.md)).

```matlab
close all force
clear global guifig
clear all
clear functions
instrreset
MasterSwitchByDAQ_WhiteBack_BlackChamber
```

The preamble is not superstition: `clear functions` defeats MATLAB's function cache, `clear global guifig` clears a stale ViRMEn handle from a previous crash, and `instrreset` releases any serial object still holding the port.

Then:

1. **Metadata** — answer in the Command Window (experimenter, strain, age in days, sex, experiment name, notes). Command Window rather than a dialog because `inputdlg` is unreliable in the hardware-GL launcher.
2. ViRMEn opens; the Arduino is opened, zeroed, and started.
3. `Waiting for first DAQ/Arduino frame pulse ...` — **now start the 2P scan.**
4. WhiteBack loads and runs to its threshold, then BlackChamber.
5. Logs are written and the session is plotted.

### Stopping a run

- **ESC** in the ViRMEn window ends it normally
- **Ctrl+C** in the Command Window
- If a fullscreen window traps the display: **Alt+Tab** away, or `Ctrl+Alt+F3` to a text console and `pkill MATLAB`

After any abort, run `instrreset` before trying again.

## Output

```
~/Documents/MATLAB/ExperimentData/
└── 20260819/
    └── Vasilis_CS_WhiteBlackSwitch_154312/
        ├── metadata.txt / metadata.mat
        ├── sess_20260819_154312_allframes.csv
        ├── sess_20260819_154312_WhiteBack.csv
        ├── sess_20260819_154312_BlackChamber.csv
        ├── sess_20260819_154312_sync.csv
        └── sess_20260819_154312_frameLogTable.mat
```

CSV columns: `phase, frame, arduino_time, matlab_time, t_rel_s, dt_ms, A0_V, A1_V, tempC, RH_pct, sketch_missed`.

`*_sync.csv` records the Arduino RTC against the MATLAB clock at the first and last frame — that is your offset for aligning with the imaging data.

## Live feedback during a run

**Panel** (`SHOW_LIVE_MONITOR`): frames, rate, dt mean/sd, dropped-in-transit, sketch-missed, temp/RH, current phase, plus a rolling frame-interval plot. Driven from inside `arduinoFrameLog('poll')`, so it shares the one port connection.

**Console** (`PRINT_EVERY`):

```
[WhiteBack] frames 50      seq 1247     29.98 Hz  dropped 0  missed 0  23.4C 41%RH
```

`PRINT_EVERY = 1` prints every frame. Fine for verification; for real recordings use 10–50 so console I/O does not compete with the render loop. Printing text is much cheaper than redrawing figures — prefer the console over a fast panel refresh.

## After the run

```matlab
plotSession                              % most recent session, found automatically
plotSession('/path/to/session/folder')   % a specific one
```

Four panels — frame timing coloured by phase, cumulative frames, analog channels, temp/RH — plus a per-phase summary:

```
phase              frames    dur (s)  rate (Hz)    dt mean      dt sd
preTrigger             12       0.40      29.97     33.361      0.388
WhiteBack             600      20.01      29.98     33.355      0.412
interval                8       0.27      29.99     33.348      0.301
BlackChamber          600      20.02      29.97     33.362      0.395

Frames lost in transit (sequence gaps): 0
```

**Check these before trusting a session:**

- `Frames lost in transit` should be **0**. Non-zero means the serial link dropped lines — reduce `PRINT_EVERY`, close other applications, check the USB cable.
- `Missed by sketch` should be **0**. Non-zero means triggers arrived faster than the Arduino could send — the trigger rate is too high for 115200 baud.
- `rate` should match your 2P scan rate.
- `dt sd` should be small relative to `dt mean`. Large scatter means jitter somewhere in the chain.

## Adapting the protocol

**Different worlds:** point `whiteBackMat` / `blackChamberMat` at your own `.mat` files and pass the matching code handles to `loadSavedExperimentIntoGui`.

**Different phase lengths:** edit `vr.frameThreshold` in each phase file.

**Closed loop with FicTrac:** change the movement function from `moveWithKeyboard` to your FicTrac movement function and start FicTrac with its TCP output enabled ([02](02-fictrac.md)).

**Writing a new phase file:** copy `WhiteBack.m`. The pattern is initialization → runtime → termination, and the runtime function must call `arduinoFrameLog('poll')` then read `latestArduinoFrame` from the base workspace — never the serial port directly.

---

Next: [07 — 3D printed parts](07-3d-printed-parts.md) · [99 — Troubleshooting](99-troubleshooting.md)

---

*JC Lab, University of Groningen. Problems with this guide? Contact Vasilis Kapantaidakis — vaskapant@gmail.com or v.kapantaidakis@student.rug.nl*

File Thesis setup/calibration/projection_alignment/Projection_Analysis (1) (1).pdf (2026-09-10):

## Optical Distance Calculation for the Projector Mirror Conical Screen Setup

Vasilis Kapantaidakis
University of Groningen
Faculty of Science and Engineering v.kapantaidakis@student.rug.nl

17 March 2026

## Goal

We want the horizontal projector mirror distance and the vertical mirror screen distance such that the projected coordinates produced by the transformation

s =

1
αr + βz , | α = 1.7, | β = −1.2,

are displayed on the conical screen with stable geometry and without additional angular distor-tion from the folded optical path.

## 1. Physical screen geometry

The conical screen is specified by:

Dmax ≈ 220 mm, | Dmin ≈ 40 mm, | H ≈ 60 mm.

Hence the corresponding radii are

Rmax =

Dmax
2

= 110 mm, Rmin =

Dmin
2

= 20 mm.

If we measure vertical position on the screen by z ∈ [0, H], from the small opening to the large opening, then the physical cone radius is

rphys(z) = Rmin +

Rmax − Rmin
H

z = 20 +

110 − 20
60

z = 20 + 1.5z.

So the physical cone slope is
drphys
dz = 1.5,

and the corresponding cone half-angle (measured from the axis) is

θphys = tan⁻¹
(1.5) ≈ 56.3

◦

## 2. Geometry implied by the transformation

The transformation is
r =

p
x

2 + y

2, s =

1
αr + βz ,

and the normalized displayed radius is

ρ = rs =

r
αr + βz .

The screen edge corresponds to ρ = 1. Therefore

r
αr + βz = 1 | =⇒ | r = αr + βz.

Rearranging,
(1 − α)r = βz.

Substituting α = 1.7 and β = −1.2,

(1 − 1.7)r = −1.2z | =⇒ | −0.7r = −1.2z,

hence
z =

0.7
1.2

r ≈ 0.5833 r,

or equivalently
r ≈ 1.714 z.

Thus the cone half-angle implied by the transformation is

θmodel = tan⁻¹

r
z
= tan⁻¹
| | (1.714) ≈ 59.7 ◦ .

Interpretation

The transformation therefore encodes a cone with half-angle about

θmodel ≈ 59.7

| | ◦ ,

while the physical screen has

θphys ≈ 56.3

| | ◦ .

These are close, so the transformation is consistent with the stated conical screen geometry up to the empirical corrections already present in the code:

LRShift = −0.15, APShift = −0.25.

Therefore the transformation is mainly responsible for the angular remapping onto the cone, while the projector mirror screen distances are determined by the optical throw geometry.

## 3. Optical path constraint

Let

- x = horizontal distance from projector beam exit to the mirror center,
- y = vertical distance from the mirror center to the mid-height of the active conical screen,
- L = total folded optical path.

With a 45◦ mirror, the path is folded by 90◦ , so

L = x + y.

Now let T be the projector throw ratio. If the projected field must cover the full usable width of the screen, then
L = T Dmax.

Since Dmax = 220 mm,
L = 220 T.

Therefore the fundamental constraint is

x + y = 220 T.

## 4. Numerical result under the standard DLP3010 assumption

If we take the commonly used assumption

T = 1.2,

then
L = 220 × 1.2 = 264 mm.

Hence
x + y = 264 mm.

This is the correct total folded optical path. The transformation itself does not uniquely determine the split between x and y; it determines the cone remapping, while only the projector optics determine the total path.

## 5. Symmetric design split

A practical stable choice is to keep the two legs nearly balanced:

x ≈ 130 mm, y ≈ 134 mm,

since
130 + 134 = 264.

Therefore the recommended optical distances are

x ≈ 130 mm

for the projector beam exit to the mirror center, and

y ≈ 134 mm

for the mirror center to the screen mid-height.

## 6. If the screen is measured from the top rim instead of the mid-height

Because the cone height is
H = 60 mm,

the top rim is 30 mm above the screen mid-height. Therefore:

ytop = y +

H
2

= 134 + 30 = 164 mm,

and the bottom rim is

ybottom = y −

H
2

= 134 − 30 = 104 mm.

So, depending on how the screen distance is measured:

mirror center to screen mid-height ≈ 134 mm, mirror center to top rim ≈ 164 mm, mirror center to bottom rim ≈ 104 mm.

## 7. Final result

The transformation confirms that the screen geometry is conical and close to the physical cone dimensions. The optical distances are then set by the projector throw condition:

x + y = 220 T.

Under the standard assumption T = 1.2,

x + y = 264 mm.

A stable and practical split is

x ≈ 130 mm, y ≈ 134 mm.

If the vertical measurement is taken to the top of the cone instead of the cone mid-height, then use
ytop ≈ 164 mm.

## Realistic Approach

Realistic interpretation of the distances

The distance
x

is the horizontal projector–mirror distance, that is, the distance traveled by the beam before reflection. Physically, this distance controls how the beam reaches the mirror and how sensitive the setup is to small alignment errors. If x is too small, small angular errors at the mirror produce larger geometric changes on the screen. If x is too large, the setup becomes unnecessarily extended without improving the cone mapping.
The distance
y

is the vertical mirror–screen distance after reflection. This is the effective projection distance after the fold and is the quantity most directly responsible for the final image size on the screen. The key point is that the projector optics depend on the total optical path, not on the fact that a mirror is present. Therefore the relevant optical constraint is

x + y = L,

where L is the total throw distance required to project the intended image width. Thus:

- x mainly affects beam conditioning and alignment sensitivity,
- y mainly affects the actual projected image size,
- x + y is the optical quantity constrained by the projector throw ratio.

In practice, this means that the transformation determines the angular remapping onto the cone, while the distances ensure that the projected field has the correct overall size.

Realistic interpretation of the transformation

The transformation
s =

1
αr + βz , | α = 1.7, | β = −1.2,

does not itself determine the optical path lengths. Instead, it determines how points in the virtual stimulus are remapped onto the conical screen.
This means that the transformation is responsible for correcting the geometry of the projected stimulus so that a point displayed by the projector appears at the intended angular position on the cone.
Hence, in a realistic interpretation:
- the transformation corrects for the conical screen geometry,
- the optical distances are chosen so that the projected field physically covers the intended part of the cone.

Because the transformation-implied cone angle is close to the physical cone angle, the mapping is already approximately matched to the hardware. Therefore the optical distances should not be treated as geometric correction parameters, but rather as projection-scale parameters.

Realistic choice of the distance split

From the projector throw condition,

x + y = 220 T.

If T = 1.2, then
x + y = 264 mm.

This total path is fixed by the optics, but the split between x and y is not unique. A realistic strategy is to avoid extreme values:

x → 0, y → 264

would place the mirror too close to the projector, making alignment highly sensitive, whereas

x → 264, y → 0 would place the image-forming region too close to the mirror, which is impractical for a conical screen.
A balanced split such as
x ≈ 130 mm, y ≈ 134 mm

is therefore realistic because it gives:

- a stable pre-reflection beam path,
- a sufficient post-reflection imaging distance,
- a symmetric folded geometry,
- reduced sensitivity to small angular misalignments.

Realistic mirror-angle choice

In the ideal folded geometry, the beam travels horizontally before reflection and vertically after reflection. This requires a direction change of

90◦

For a planar mirror, the reflected direction is obtained by symmetry about the mirror normal, so the mirror normal bisects the angle between incident and reflected rays.
Thus the required mirror angle is

θmirror = 45◦

This is the correct design angle. In practice, however, real hardware introduces small devi-ations:

- the projector may not be perfectly level,
- the mirror mount may not be perfectly centered,
- the screen center may not be exactly above the mirror center,
- machining tolerances may shift the real geometry.

Therefore, in a realistic setup, the best strategy is:

- use
| 45◦

as the nominal design angle,

- allow a small adjustment around this value during alignment.

A typical realistic tuning range is
44◦ | to 46◦ ,

or slightly wider if needed. This adjustment is not used to redefine the cone mapping, but only to compensate for small hardware offsets.
Hence the realistic conclusion is:

θmirror ≈ 45◦ nominal, with small fine adjustment around it.

Realistic measurement convention

In practice, the mirror–screen distance must be defined relative to a specific reference point on the cone. The mathematically most natural reference is the screen mid-height. However, experimentally one may instead measure to the top rim or bottom rim.
If y denotes the mirror center to screen mid-height distance, then

ytop = y +

H
2
, | ybottom = y −

H
2

For
H = 60 mm, y = 134 mm,

this gives
ytop = 164 mm, ybottom = 104 mm.

Thus, in real setup work, it is important to specify whether the vertical distance is measured to:

- the mid-height of the cone,
- the top rim,
- or the bottom rim.

Realistic practical conclusion

The realistic interpretation of the system is therefore:

1. The transformation sets the angular remapping required by the cone.
2. The projector throw determines the total optical path:

x + y = 220 T.

3. The mirror folds the path but does not change the optical throw requirement.
4. A balanced split of the total path is preferable for alignment stability.
5. The mirror angle should be designed at

45◦

and only fine-tuned slightly in practice.

Under the standard assumption T = 1.2, the realistic recommended distances remain

x ≈ 130 mm, | y ≈ 134 mm, | θmirror ≈ 45◦

## Ring Design for Conical Screen Mounting

Given screen geometry

Dtop = 220 mm, | Dbottom = 40 mm, | H = 60 mm
Rtop = 110 mm, | Rbottom = 20 mm

Cone angle

The cone half-angle relative to the vertical axis is:

θ = tan⁻¹

Rtop − Rbottom
H
= tan⁻¹
110 − 20

60
= tan⁻¹
(1.5) ≈ 56.3

◦

The complementary angle relative to the ring plane is:

ϕ = 90◦ − θ ≈ 33.7

◦

Top ring design

- Inner diameter:
Dtop = 220 mm
- Slot angle (relative to ring plane): ϕ ≈ 33.7

◦

- Slot direction:

– angled inward toward the cone axis

Bottom ring design

- Inner diameter:
Dbottom = 40 mm
- Slot angle (relative to ring plane): ϕ ≈ 33.7

◦

- Slot direction:

– angled outward away from the cone axis

Axial spacing

The vertical distance between rings must be:

H = 60 mm

Final design constraints

Dtop = 220 mm
Dbottom = 40 mm
H = 60 mm
ϕ ≈ 33.7

◦

Practical fabrication note

In practice, use:

ϕ ≈ 34◦

to simplify manufacturing, and allow small tolerance for film insertion and tensioning.

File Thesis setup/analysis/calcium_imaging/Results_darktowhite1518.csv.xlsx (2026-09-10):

 | Label | Area1 | Mean1 | MinThr1 | MaxThr1 | Area2 | Mean2 | MinThr2 | MaxThr2 | Area3 | Mean3 | MinThr3 | MaxThr3 | Area4 | Mean4 | MinThr4 | MaxThr4 | Area5 | Mean5 | MinThr5 | MaxThr5 | 9.829 | 21.433 | 5.551 | 8.9 | 0.3334 | 11.3718 | 12.3564 | -4.2334
1 | 20052026_00015_darktowhite1518.tif | 3.485 | 60.576 | -32768 | 32767 | 3.467 | 72.18 | -32768 | 32767 | 1.648 | 56.298 | -32768 | 32767 | 2.8 | 59.647 | -32768 | 32767 | 2.8 | 50.747 | -32768 | 32767 | -1.213 | 12.674 | 11.741 | 0.909 | -463.8272346 | 11.45113351 | -4.980415008 | -121.4721028
2 | 20052026_00015_darktowhite1518.tif | 3.485 | 54.748 | -32768 | 32767 | 3.467 | 68.635 | -32768 | 32767 | 1.648 | 67.702 | -32768 | 32767 | 2.8 | 56.87 | -32768 | 32767 | 2.8 | 55.961 | -32768 | 32767 | 12.208 | 19.428 | 14.736 | 6.259 | 3561.667666 | 70.84366591 | 19.25803632 | -247.8480654
3 | 20052026_00015_darktowhite1518.tif | 3.485 | 69.873 | -32768 | 32767 | 3.467 | 77.093 | -32768 | 32767 | 1.648 | 72.401 | -32768 | 32767 | 2.8 | 63.924 | -32768 | 32767 | 2.8 | 57.665 | -32768 | 32767 | 10.484 | 17.792 | 20.974 | 5.764 | 3044.571086 | 56.45720115 | 69.74199605 | -236.1553361
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

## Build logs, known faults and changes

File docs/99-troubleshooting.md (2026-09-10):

# 99 — Troubleshooting

Every error hit while building this rig, with its cause and fix. Search this page by the error text.

---

## Camera / FicTrac

### `Failed to open ... The device is controlled by another application. (0xE1018006)`

A GigE camera accepts **one controlling application at a time**. Pylon Viewer, an earlier `configGui` still sitting at "Hit ENTER to exit", or a previous `fictrac` is holding it.

```bash
pkill -f pylonviewer; pkill -f configGui; pkill -f fictrac
sleep 8
pgrep -a "pylonviewer|configGui|fictrac" || echo "camera free"
```

The `sleep 8` matters: after a client dies the camera keeps its control channel until the heartbeat expires, so an immediate retry fails identically. If it persists, power-cycle the camera.

### `The Wayland connection experienced a fatal error: Protocol error`

FicTrac's OpenCV/Qt GUI does not work under Wayland. Switch the session to **Xorg** — [00](00-user-setup.md). Check with `echo $XDG_SESSION_TYPE` (want `x11`).

### `QStandardPaths: runtime directory '/run/user/1000' is not owned by UID 0`

You ran a GUI application with `sudo`. GigE cameras need no root — drop it.

### Camera pings but video does not stream

**Jumbo frames.** The host MTU is 9000 but the link cannot carry it. Small packets (ping) pass, large ones (video) do not.

```bash
ping -M do -s 8972 -c 3 192.168.4.3     # 100% loss = jumbo broken
sudo ip link set <iface> mtu 1500
```

Pin it: `nmcli con mod "<connection-name>" 802-3-ethernet.mtu 1500`. Also check the camera's own **GevSCPSPacketSize** does not exceed the host MTU. [01](01-basler-camera.md)

### Camera not found at all

```bash
ip -br addr show <iface>              # link UP? host IP set?
ip neigh show | grep <subnet>         # a 00:30:53:* MAC = Basler
/opt/pylon/bin/ipconfigurator &       # finds cameras with a wrong IP
```

### `fatal error: pylon/usb/BaslerUsbInstantCameraArray.h: No such file or directory`

Modern Pylon removed the transport-specific headers. Apply the one-line patch in [02](02-fictrac.md).

### `E: Unable to locate package libavresample-dev`

Removed in FFmpeg 5 / Ubuntu 24.04. Do not install it; FicTrac builds without it.

### configGui prompts answer themselves

You typed ahead. Characters queue in stdin and later prompts consume them — you silently keep the sample's calibration. Answer **one prompt at a time**. Remember **y/n go to the terminal, ENTER/ESC go to the image window** (click it first). [02](02-fictrac.md)

### Ball circle fit looks wrong

Duplicate click points from dragging. Use single deliberate clicks, 6–8 spread around the edge. Check `fictrac-configImg.png` — the red circle must sit on the ball. To start clean:

```bash
sed -i '/^roi_/d; /^c2a_r/d; /^c2a_t/d' config.txt
```

### `Error! Recorder processing thread unable to set thread priority!`

Harmless. FicTrac asks for real-time scheduling priority and Linux declines.

---

## MATLAB

### `License Manager Error -9 — Your username does not match`

The activation is bound to a different OS login name. Fix in the MathWorks License Center: deactivate the computer, re-activate with **Operating System User Name** = your exact Linux username, download the new licence, reactivate locally. [03](03-matlab.md)

### `error while loading shared libraries: libncurses.so.5`

Not packaged in Ubuntu 24.04. Install the 22.04 `.deb`s. [03](03-matlab.md)

### Segfault at `glViewport` in `virmenOpenGLRoutines.mexa64`

```
Software OpenGL : 1
[0] .../sys/opengl/lib/glnxa64/libGL.so.1 ... glViewport
[1] .../virmen/bin/engine/virmenOpenGLRoutines.mexa64
```

MATLAB was launched with **`-softwareopengl`**. ViRMEn's GLFW engine needs hardware libGL. Run experiments from the **hardware-GL** launcher. [03](03-matlab.md)

### ViRMEn design panels are blank

The opposite case — you need `-softwareopengl` for the editor. Use the **DESIGN** launcher. `opengl info` → `Software` should read `'true'`.

### `Switching to software OpenGL rendering at runtime on unix is not supported`

Correct — it must be a launch flag on Linux, which is why there are two launchers.

### The desktop icon behaves differently from the terminal

GNOME caches `.desktop` files. After editing one, **log out and back in**.

### `Open failed: Port: /dev/ttyACM0 is not available. Available ports: /dev/ttyS4`

MATLAB R2014b on Linux only recognises `/dev/ttyS*`. Symlink it and add the udev rule. [05](05-arduino-daq.md)

### `/dev/ttyS101` disappeared after a reboot

`/dev` is rebuilt at boot. That is what the udev rule is for. [05](05-arduino-daq.md)

### `Error using guidata — H must be the handle to a figure or figure descendent`

Stale ViRMEn state after a crash: a leftover figure's resize callback fires against a dead `guifig`.

```matlab
close all force
clear global guifig
clear all
clear functions
rehash
```

If it persists, restart MATLAB — after a segfault the Java/graphics state can be corrupted beyond what `clear` fixes.

### `Function definitions are not permitted in this context`

R2014b **scripts** cannot contain local functions (that arrived in R2016b). Inline the helpers or convert the file to a function.

### `Undefined function 'serialport'`

R2019b+ API. R2014b uses legacy `serial()` / `fopen` / `fgetl` / `fread`. Same for `configureTerminator`, `readline`, `yyaxis`, `isgraphics`, `datetime(...,'ConvertFrom','posixtime')`.

### An edit to a `.m` file has no effect

MATLAB caches functions in memory. `clear functions; rehash` — or restart. Verify what is actually on disk with `grep`, and what MATLAB resolves with `which <name>`.

### `Reference to non-existent field 'lastArduinoFrame'`

An old copy of a phase file is on the path. Confirm the installed file is the current one and `clear functions`.

---

## ViRMEn build

### `Unsupported compilation architecture. See ViRMEn manual`

No `GLNXA64` branch in `virmenMake.m`. Add it. [04](04-virmen.md)

### `error: C++ style comments are not allowed in ISO C90`

The non-GLFW `mex(f)` call compiles in C90. Add `CFLAGS="$CFLAGS -std=c99 -fPIC"`. [04](04-virmen.md)

### `Index exceeds matrix dimensions` in `updateFigures` line ~494

The transformation list is empty because `updateFigures.m` has no `GLNXA64` case, so it never sees your `.mexa64` files. Add the case in **both** the movements and transformations blocks. [04](04-virmen.md)

```bash
grep -c "GLNXA64" ~/Documents/MATLAB/virmen/bin/gui/updateFigures.m    # expect 2
```

### `cannot find -lglfw` / `-lGL`

Missing dev packages — the linker needs the bare `.so` symlinks:

```bash
sudo apt-get install -y libglfw3-dev libgl1-mesa-dev libglu1-mesa-dev
ls -l /usr/lib/x86_64-linux-gnu/libglfw.so /usr/lib/x86_64-linux-gnu/libGL.so
```

### gcc pointer-type warnings during `virmenMake`

Harmless. 2016 code, 2024 compiler.

---

## Arduino

### Port greyed out in the IDE / `avrdude: ser_open(): can't open device`

Not in the `dialout` group, or not logged out and back in since being added. [00](00-user-setup.md)

### Sketch will not compile

Missing libraries. Install **RTClib** (Adafruit) and **DHT sensor library** (Adafruit) — accept **Install All** for the Unified Sensor dependency. [05](05-arduino-daq.md)

### Humidity always `nan`

Fixed in v6. The DHT22 needs 2 s between samples; earlier versions forced two reads back to back, so the second always failed. Use `daq_frame_logger_v6.ino`.

### MATLAB cannot open the port while the IDE is open

Close the Arduino IDE **Serial Monitor**. One program per port.

### Zero frames captured, but no error

The port opened; the DAQ is not triggering. Check the 2P is scanning and the BNC reaches **D2**.

### Dropped frames / sketch-missed non-zero

- `dropped` (sequence gaps) → serial link losing lines. Reduce `PRINT_EVERY`, lower the panel refresh, close other applications.
- `missed` (sketch counter) → triggers arriving faster than 115200 baud can carry them.

---

## Display

### VR window is not fullscreen

`FULLSCREEN_VR = false` in the master script config. Note that on a **single** display, fullscreen hides the live monitor panel — that is expected. [06](06-experiment-workflow.md)

### Projector mirrors the laptop

X sees one display. Extend it:

```bash
xrandr --listmonitors
xrandr --output <PROJECTOR> --auto --right-of <LAPTOP>
```

then `VR_MONITOR = 2`. [06](06-experiment-workflow.md)

### The live monitor panel vanishes when the VR window opens

Fullscreen covers it. Either run windowed, or use the projector as a second display and keep the panel on the laptop screen. The console output (`PRINT_EVERY`) is never hidden.

---

## General principles

1. **One program per device** — camera and serial port both.
2. **Wait ~8 s** after killing a camera client.
3. **`clear functions`** after editing MATLAB code.
4. **Log out and back in** after changing groups or `.desktop` files.
5. **Check the actual file on disk** (`grep`) rather than assuming an edit was saved.
6. **Test each layer alone** before combining — camera in Pylon Viewer, then FicTrac; Arduino in Serial Monitor, then MATLAB; ViRMEn with tennisCourt, then your world.

---

*JC Lab, University of Groningen. Problems with this guide? Contact Vasilis Kapantaidakis — vaskapant@gmail.com or v.kapantaidakis@student.rug.nl*

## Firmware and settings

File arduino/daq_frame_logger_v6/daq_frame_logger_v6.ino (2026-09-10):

/*
  daq_frame_logger_v6.ino
  ------------------------------------------------------------------
  Arduino Uno R3  -  DAQ frame logger with RTC, DHT22 and IR illuminator

  Pin map (as wired)
    DAQ frame trigger   D2   INT0, BNC centre; shield -> Arduino GND
    IR LED array        D5   -> WPM411 (IRF520) SIG   [PWM capable]
                             V- = switching leg, V+ unused
    DHT22 DATA          D7   +10k pull-up to 5V if bare 4-pin sensor
    DS3231              A4 SDA / A5 SCL
    DAQ analog in       A0, A1

  Serial commands (Serial Monitor at 115200, or from MATLAB)
    S  start streaming        X  stop streaming
    Z  zero frame counter     R  print statistics now
    1  LEDs full on           0  LEDs off
    B<n>  LED brightness 0-255 (e.g. B128)
    T  DHT self-test: 5 reads with the trigger interrupt detached
    H  toggle 1 Hz heartbeat  ?  print header block

  Output, one line per DAQ trigger:
    D,seq,epoch_s,ms,micros,a0,a1,tempC,rh,missed

  v6 fix: the DHT22 needs 2 s of dead time between samples. v4/v5
  forced BOTH readTemperature() and readHumidity(), so the humidity
  call hit the sensor milliseconds after the temperature call and
  always returned NaN. Now one call forces a fresh sample and the
  other reads the same packet from cache. The 60 ms retry loop had
  the same fault and is gone; a failed read is simply retried on the
  next 2 s cycle, which also keeps the loop non-blocking.
  ------------------------------------------------------------------
*/

#include <Wire.h>
#include <RTClib.h>
#include <DHT.h>

// ------------------------- pin map -------------------------------
const uint8_t PIN_TRIG     = 2;
const uint8_t PIN_LED_GATE = 5;
const uint8_t PIN_DHT      = 7;
const uint8_t CH_A         = A0;
const uint8_t CH_B         = A1;

#define DHTTYPE DHT22              // change to DHT11 if that's the part

// ------------------------- config --------------------------------
const uint32_t BAUD           = 115200;
const uint16_t DHT_PERIOD_MS  = 2200;   // >= 2000; sensor dead time
const uint16_t DHT_FORCE_MS   = 6000;   // read regardless once this stale
const uint16_t DHT_GUARD_MS   = 150;    // prefer to read between bursts
const uint16_t RTC_PERIOD_MS  = 1000;
const uint16_t STAT_PERIOD_MS = 1000;
const uint16_t MIN_TRIG_US    = 200;    // reject edges closer than this

// ------------------------- globals -------------------------------
RTC_DS3231 rtc;
DHT dht(PIN_DHT, DHTTYPE);

volatile uint32_t trigSeq      = 0;
volatile uint32_t trigMicros   = 0;
volatile uint32_t trigMillis   = 0;
volatile bool     trigPending  = false;
volatile uint32_t lastEdgeUs   = 0;
volatile uint32_t missedFrames = 0;

uint32_t rtcEpoch = 0, rtcAnchorMs = 0;
uint32_t lastDhtMs = 0, lastRtcMs = 0, lastStatMs = 0, lastDhtGoodMs = 0;
uint32_t statSeqMark = 0;
uint16_t dhtOk = 0, dhtFail = 0;
uint8_t  ledLevel = 255;
float    lastRateHz = 0;

float tempC = NAN, rh = NAN;
bool  streaming = false, rtcOk = false, heartbeat = true;

// ------------------------- ISR -----------------------------------
void onFrameTrigger() {
  uint32_t now = micros();
  if (now - lastEdgeUs < MIN_TRIG_US) return;   // glitch / ringing
  lastEdgeUs = now;
  if (trigPending) missedFrames++;              // previous frame unsent
  trigMicros = now;
  trigMillis = millis();
  trigSeq++;
  trigPending = true;
}

// ------------------------- helpers -------------------------------
void setLeds(uint8_t level) {
  ledLevel = level;
  if (level == 0)        digitalWrite(PIN_LED_GATE, LOW);
  else if (level == 255) digitalWrite(PIN_LED_GATE, HIGH);
  else                   analogWrite(PIN_LED_GATE, level);   // ~980 Hz
}

void anchorClock() {
  if (!rtcOk) return;
  DateTime t = rtc.now();
  rtcEpoch    = t.unixtime();
  rtcAnchorMs = millis();
}

// ONE forced sample, then the companion value from the same packet.
// Forcing both would hit the sensor inside its 2 s dead time and the
// second call would always return NaN.
bool readDht() {
  float t = dht.readTemperature(false, true);   // celsius, force fresh
  float h = dht.readHumidity(false);            // same packet, cached

  if (isnan(t) || isnan(h)) { dhtFail++; return false; }

  tempC = t;
  rh    = h;
  dhtOk++;
  lastDhtGoodMs = millis();
  return true;
}

// Five reads with the trigger interrupt detached, spaced past the
// sensor's dead time. Run once with the LEDs on, then send '0' and
// run again to isolate power-rail droop from interrupt interference.
void selfTest() {
  Serial.println(F("#selftest,start - interrupt detached"));
  Serial.print(F("#selftest,leds=")); Serial.println(ledLevel);
  detachInterrupt(digitalPinToInterrupt(PIN_TRIG));

  uint8_t good = 0;
  for (uint8_t i = 0; i < 5; i++) {
    float t = dht.readTemperature(false, true);
    float h = dht.readHumidity(false);
    Serial.print(F("#test,")); Serial.print(i); Serial.print(',');
    if (isnan(t) || isnan(h)) {
      Serial.println(F("FAIL"));
    } else {
      good++;
      Serial.print(t, 1); Serial.print(','); Serial.println(h, 1);
    }
    delay(2200);                    // respect the dead time
  }

  Serial.print(F("#selftest,good=")); Serial.print(good); Serial.println(F("/5"));
  if (good == 5)     Serial.println(F("#selftest,clean without the ISR -> interrupt is the cause"));
  else if (good > 0) Serial.println(F("#selftest,intermittent -> decoupling / signal integrity"));
  else               Serial.println(F("#selftest,none -> send '0' and retest; if still 0, check wiring"));

  attachInterrupt(digitalPinToInterrupt(PIN_TRIG), onFrameTrigger, RISING);
  Serial.println(F("#selftest,end - interrupt reattached"));
}

void printStats() {
  uint32_t seqNow, miss;
  noInterrupts(); seqNow = trigSeq; miss = missedFrames; interrupts();

  Serial.print(F("#stat,frames="));  Serial.print(seqNow);
  Serial.print(F(",rate="));         Serial.print(lastRateHz, 1);
  Serial.print(F("Hz,missed="));     Serial.print(miss);
  Serial.print(F(",dhtOk="));        Serial.print(dhtOk);
  Serial.print(F(",dhtFail="));      Serial.print(dhtFail);
  Serial.print(F(",T="));
  if (isnan(tempC)) Serial.print(F("nan")); else Serial.print(tempC, 1);
  Serial.print(F(",RH="));
  if (isnan(rh))    Serial.print(F("nan")); else Serial.print(rh, 1);
  Serial.print(F(",age="));
  Serial.print(lastDhtGoodMs ? (millis() - lastDhtGoodMs) : 0);
  Serial.print(F("ms,led="));        Serial.print(ledLevel);
  Serial.print(F(",stream="));       Serial.println(streaming ? 1 : 0);
}

void printHeader() {
  Serial.println(F("#fmt,seq,epoch_s,ms,micros,a0,a1,tempC,rh,missed"));
  Serial.println(F("#pins,trig=D2,gate=D5,dht=D7,i2c=A4/A5,analog=A0/A1"));
  Serial.print(F("#rtc,")); Serial.println(rtcOk ? F("ok") : F("FAIL"));
  Serial.print(F("#dht,")); Serial.println(dhtOk ? F("ok") : F("no valid read yet"));
  printStats();
}

// ------------------------- setup ---------------------------------
void setup() {
  Serial.begin(BAUD);
  while (!Serial) { ; }

  pinMode(PIN_LED_GATE, OUTPUT);
  setLeds(255);                    // illuminator on at boot

  pinMode(PIN_TRIG, INPUT);        // INPUT_PULLUP if DAQ is open-collector
  dht.begin();

  Wire.begin();
  rtcOk = rtc.begin();
  if (rtcOk) {
    if (rtc.lostPower()) rtc.adjust(DateTime(F(__DATE__), F(__TIME__)));
    anchorClock();
  }

  delay(2000);                     // DHT22 needs this before first read
  readDht();
  lastDhtMs = millis();

  attachInterrupt(digitalPinToInterrupt(PIN_TRIG), onFrameTrigger, RISING);
  printHeader();
}

// ------------------------- loop ----------------------------------
void loop() {

  // ---- serial commands ----
  while (Serial.available()) {
    char c = Serial.read();
    switch (c) {
      case 'S': case 's':
        noInterrupts(); trigPending = false; interrupts();
        streaming = true; anchorClock();
        Serial.println(F("#start")); break;
      case 'X': case 'x':
        streaming = false; Serial.println(F("#stop")); break;
      case 'Z': case 'z':
        noInterrupts(); trigSeq = 0; missedFrames = 0; trigPending = false; interrupts();
        statSeqMark = 0; Serial.println(F("#zero")); break;
      case '1': setLeds(255); Serial.println(F("#leds,255")); break;
      case '0': setLeds(0);   Serial.println(F("#leds,0"));   break;
      case 'B': case 'b': {
        long v = Serial.parseInt();
        setLeds((uint8_t)constrain(v, 0, 255));
        Serial.print(F("#leds,")); Serial.println(ledLevel);
        break;
      }
      case 'T': case 't': selfTest(); break;
      case 'H': case 'h':
        heartbeat = !heartbeat;
        Serial.print(F("#heartbeat,")); Serial.println(heartbeat ? 1 : 0); break;
      case 'R': case 'r': printStats(); break;
      case '?': printHeader(); break;
      default: break;
    }
  }

  uint32_t now = millis();

  // ---- absolute-time anchor, once per second ----
  if (now - lastRtcMs >= RTC_PERIOD_MS) { lastRtcMs = now; anchorClock(); }

  // ---- DHT22: read between bursts if possible, force if stale ----
  bool due   = (now - lastDhtMs >= DHT_PERIOD_MS);
  bool quiet = (now - trigMillis > DHT_GUARD_MS);
  bool stale = (now - lastDhtMs >= DHT_FORCE_MS);
  if (due && (quiet || stale)) { lastDhtMs = now; readDht(); }

  // ---- once-per-second frame statistics ----
  if (now - lastStatMs >= STAT_PERIOD_MS) {
    uint32_t seqNow;
    noInterrupts(); seqNow = trigSeq; interrupts();
    lastRateHz  = (seqNow - statSeqMark) * 1000.0 / (now - lastStatMs);
    statSeqMark = seqNow;
    lastStatMs  = now;
    if (heartbeat) printStats();
  }

  // ---- one CSV line per DAQ frame ----
  if (trigPending) {
    uint32_t seq, us, ms, miss;
    noInterrupts();
    seq = trigSeq; us = trigMicros; ms = trigMillis; miss = missedFrames;
    trigPending = false;
    interrupts();

    int va = analogRead(CH_A);
    int vb = analogRead(CH_B);

    if (streaming) {
      uint32_t elapsed = ms - rtcAnchorMs;
      Serial.print('D');                          Serial.print(',');
      Serial.print(seq);                          Serial.print(',');
      Serial.print(rtcEpoch + elapsed/1000UL);    Serial.print(',');
      Serial.print((uint16_t)(elapsed % 1000UL)); Serial.print(',');
      Serial.print(us);                           Serial.print(',');
      Serial.print(va);                           Serial.print(',');
      Serial.print(vb);                           Serial.print(',');
      if (isnan(tempC)) Serial.print(F("nan")); else Serial.print(tempC, 2);
      Serial.print(',');
      if (isnan(rh))    Serial.print(F("nan")); else Serial.print(rh, 2);
      Serial.print(',');
      Serial.println(miss);
    }
  }
}

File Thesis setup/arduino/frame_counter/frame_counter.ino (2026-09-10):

const byte ttlPin = 2;

volatile unsigned long frameCount = 0;
volatile bool newFrame = false;

void frameISR() {
  frameCount++;
  newFrame = true;
}

void setup() {
  pinMode(ttlPin, INPUT);
  Serial.begin(115200);
  attachInterrupt(digitalPinToInterrupt(ttlPin), frameISR, RISING);
}

void loop() {
  static unsigned long lastSent = 0;

  noInterrupts();
  unsigned long countCopy = frameCount;
  bool flagCopy = newFrame;
  newFrame = false;
  interrupts();

  if (flagCopy && countCopy != lastSent) {
    lastSent = countCopy;
    Serial.print("FRAME,");
    Serial.println(countCopy);
  }
}

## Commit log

2026-09-10 Two photon setup - JC Lab: full replication documentation
    Setup and operation guide for the two-photon imaging and behaviour rig:
    Basler GigE camera, FicTrac spherical treadmill tracking, ViRMEn virtual
    worlds on a conical screen, and Arduino frame-trigger timestamping, all
    on Ubuntu 24.04 with MATLAB R2014b.
    Contents:
    RUN-AN-EXPERIMENT.md day-of-experiment checklist
    docs/00-07 install path, one file per subsystem
    docs/99 troubleshooting index keyed by error text
    matlab/ experiment scripts (R2014b compatible)
    arduino/ daq_frame_logger_v6 sketch
    patches/ source patches for FicTrac (modern Pylon) and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
    [holder_w50_h75_lr_M6.step, post_L50_A_M6.step]
2026-09-10 Add Thesis setup: conical screen design, calibration and 3D prints
    [Flyplate5.stl, Full screen 2mm groove (1).stl, Full screen 2mm groove (2).stl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]
